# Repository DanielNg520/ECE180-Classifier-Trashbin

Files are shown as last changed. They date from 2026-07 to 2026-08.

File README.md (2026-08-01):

<p align="center">
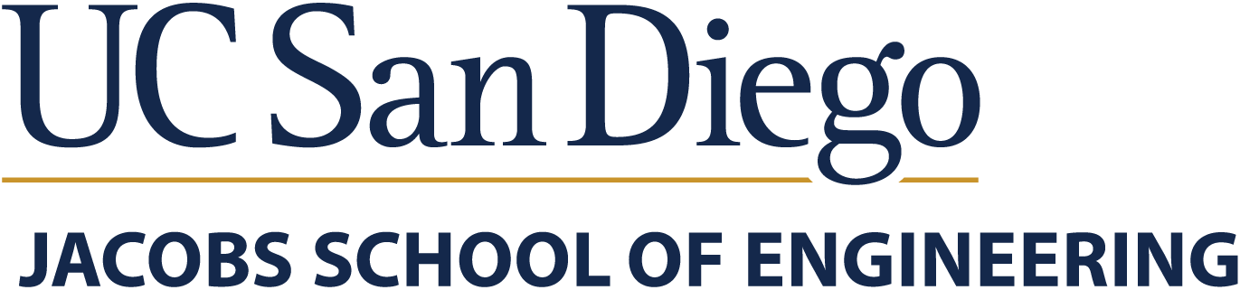
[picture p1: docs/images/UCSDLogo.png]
UC San Diego
  
</p>

# UCSD ECE 180 Summer 2026 Team 12 Final Project: Bin-ary Sort

*Waste sorting with computer vision, on the Arduino UNO Q.*

<p align="center">
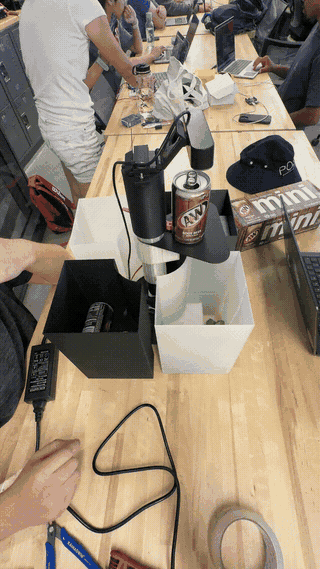
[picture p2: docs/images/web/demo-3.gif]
Bin-ary Sort classifying a can and rotating it to the correct bin
  
</p>

## Team Members

| Name | Major | Year |
|---|---|---|
| Colin Hua | ECE — Electrical Engineering | 2027 |
| Duy Nguyen | ECE — Computer Engineering | 2027 |
| Aram Zarate Ubario | ECE — Computer Engineering | 2027 |

**Course:** ECE 180 — Prof. Silberman, UC San Diego, Summer 2026

## Project Overview

Bin-ary Sorter is a smart trashbin that sorts your trash for you. You drop an
item in, and it lands in the right one of four bins. No phone, no app, no cloud
call, and nothing for the user to do.

A USB camera on top of the bin looks down and grabs a frame. A fine-tuned
**MobileNetV3-Large** classifies it into one of 30 waste classes from the Kaggle
dataset, that label collapses down to a bin number, and a NEMA-17 stepper
rotates the pole to that bin. All of the inference runs **on the board itself**,
on the UNO Q's Qualcomm Dragonwing Linux side. The STM32 MCU sitting on the same
board handles the real-time motor timing, and the two halves talk over Arduino's
**RouterBridge** RPC. Plug it in and it starts: both the classifier and the motor
controller come up on their own at boot.

If the model isn't sure, the bin doesn't guess. It sends the frame to our web
dashboard and asks a person which bin it should have been, and that answer goes
back into the training set for the next retrain.

## Goals

### Original Goals
- Train a transfer-learning waste classifier accurate enough to run quantized on an edge MPU
- Run inference fully on-device on the Arduino UNO Q (no cloud inference)
- Drive a rotating-pole sorting mechanism from the classification result
- Build a web dashboard showing live status and classification confidence

### Goals We Met
- MobileNetV3-Large fine-tuned to **89.1% test accuracy / 0.890 macro-F1** across 30 classes
- Exported to ONNX + three TFLite variants with **measured** per-variant accuracy, size, and latency
- Full on-device pipeline: camera → classify → bin index → stepper move, autostarted at boot
- **2-category sorting** through the single-axis rotating-pole chassis — later extended to 4 (see Stretch Goals)
- Web dashboard with correct/wrong human feedback (reinforced-learning loop)
- Second motor (servo arm) added to the mechanism late in the schedule

### Stretch Goals
- **4-category sorting** through the 2-axis double-motored rotating system — *Done*
- Federated learning across bins for a network effect — *Done*
- Higher-throughput continuous-feed sorting rather than one item at a time — *in progress*

## System Hardware

| Component | Purpose |
|---|---|
| Arduino UNO Q (Qualcomm Dragonwing QRB2210) | Primary compute — quad Cortex-A53 + Adreno 702, Debian Linux |
| STM32U585 MCU (Zephyr, on-board) | Real-time stepper/servo control, reached over RouterBridge RPC |
| USB webcam | Item capture at the drop chute |
| NEMA-17 stepper + driver | Rotates the sorting pole to the target bin |
| Servo arm | Second-stage actuation (added late; `SERVO_ENABLED` gate) |

## Model & Dataset

**Dataset:** [Recyclable and Household Waste Classification](https://www.kaggle.com/datasets/alistairking/recyclable-and-household-waste-classification)
— 30 classes, ~15k images, each class split into `default` (studio) and
`real_world` (cluttered) subsets.

We split it 70/15/15, stratified by *(class, subset)*, so the `real_world`
images show up in val and test in the same proportion as in training. This
matters more than it sounds: if we had let the studio shots dominate the test
set, our numbers would look better than what the bin's camera actually sees.

| Metric | Value |
|---|---|
| Test accuracy (fp32) | **89.08%** |
| Macro-F1 | **0.890** |
| Parameters | 4.24 M |
| `default` vs `real_world` accuracy | 89.2% vs 88.9% (no meaningful domain gap) |

Training is a two-stage fine-tune (head-only warmup, then full fine-tune) with
AdamW + cosine schedule, label smoothing 0.1, AMP, EMA weights, MixUp/CutMix,
class-balanced sampling, and augmentation meant to imitate a cheap camera. None
of that survives into deployment. What we export is one plain network.

### Quantization results

We re-scored every exported variant on the real test set instead of assuming the
quantized model kept the fp32 accuracy:

| Variant | Test acc | Size | Recommended threshold |
|---|---|---|---|
| fp32 | 89.08% | 17.1 MB | 0.75 |
| dynamic-int8 | 87.37% | 4.63 MB | 0.55 |
| **static-int8 (shipped)** | **86.36%** | **4.87 MB** | **0.80** |

**We ship static-int8.** It costs us 2.7 points of accuracy against fp32, but
it is 3.5× smaller, it is the fastest of the three on the board, and its
quantization ranges are calibrated on `real_world` training images so they line
up with what the camera sees. The confidence gate covers the accuracy we gave
up: at its measured 0.80 threshold, the predictions the bin accepts on its own
are still 95.0% correct, and everything below that goes to a person.

### Measured on-device latency

Benchmarked on the UNO Q itself (aarch64, quad Cortex-A53, TFLite XNNPACK CPU
delegate, 256×256 int8 input, 50 timed invocations after warmup):

| Threads | Median | Mean | Min – Max |
|---|---|---|---|
| 1 | 79.8 ms | 80.1 ms | 79.2 – 83.1 ms |
| **4 (shipped)** | **26.5 ms** | **27.3 ms** | **26.0 – 35.1 ms** |

`infer_uno_q.py` runs the interpreter with `num_threads=4`, so **~27 ms per
frame** is what a real classification costs us. That is nothing next to how long
the stepper takes to settle, so the model is never the slow part of a drop
cycle. This is inference only; camera capture and preprocessing sit on top of
it. We never needed the GPU delegate.

## Mechanical Design

Four bins sit in a round casing around a **rotating pole**. The pole always
takes the shorter way around to the target bin, clockwise or counter-clockwise,
and a tie goes clockwise. The move blocks until the pole actually gets there, so
when the software gets an acknowledgment it means the motion finished, not just
that the command was received.

We rebuilt the chassis once. The first design failed during seam testing and had
to be reprinted, which is the revision block you can see in the Gantt chart
below.

### Final design renders

| | |
|---|---|
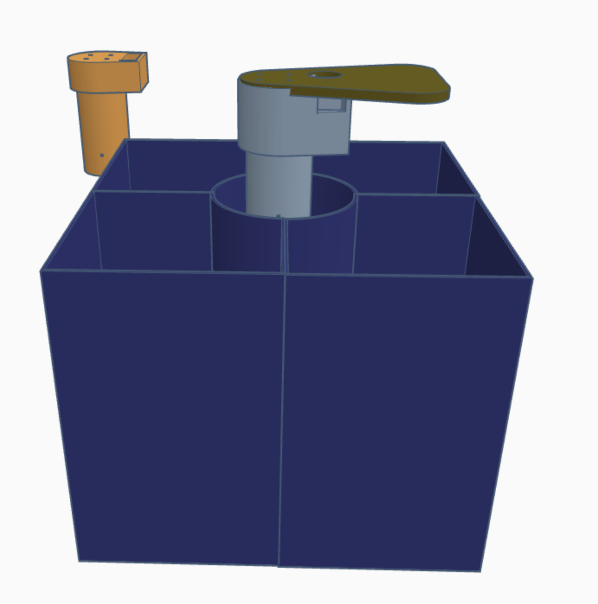
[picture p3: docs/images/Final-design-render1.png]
Final design render 1
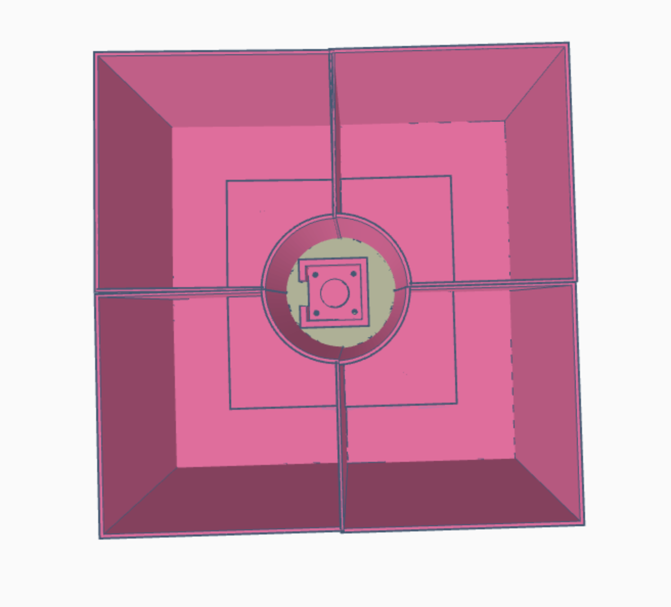
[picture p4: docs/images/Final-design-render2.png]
Final design render 2
|  |  |

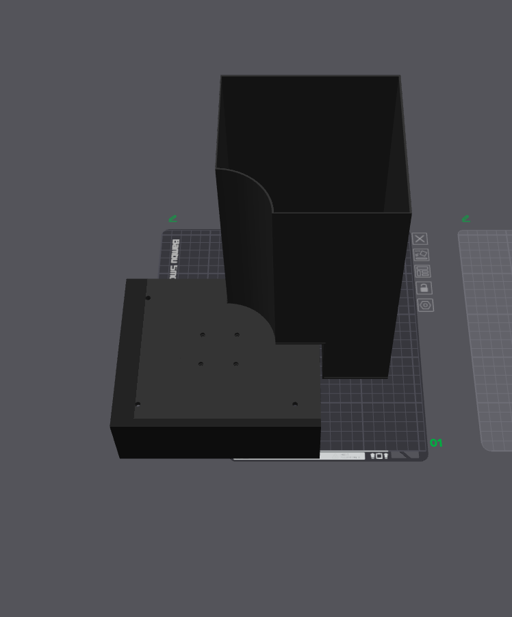
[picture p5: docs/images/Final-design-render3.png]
Final design render 3


### Double-motored rotating pole

This is the 2-axis mechanism that got us from 2 categories to 4. The stepper
rotates the pole to the target bin, then the servo arm sweeps the item off the
platform and into it.

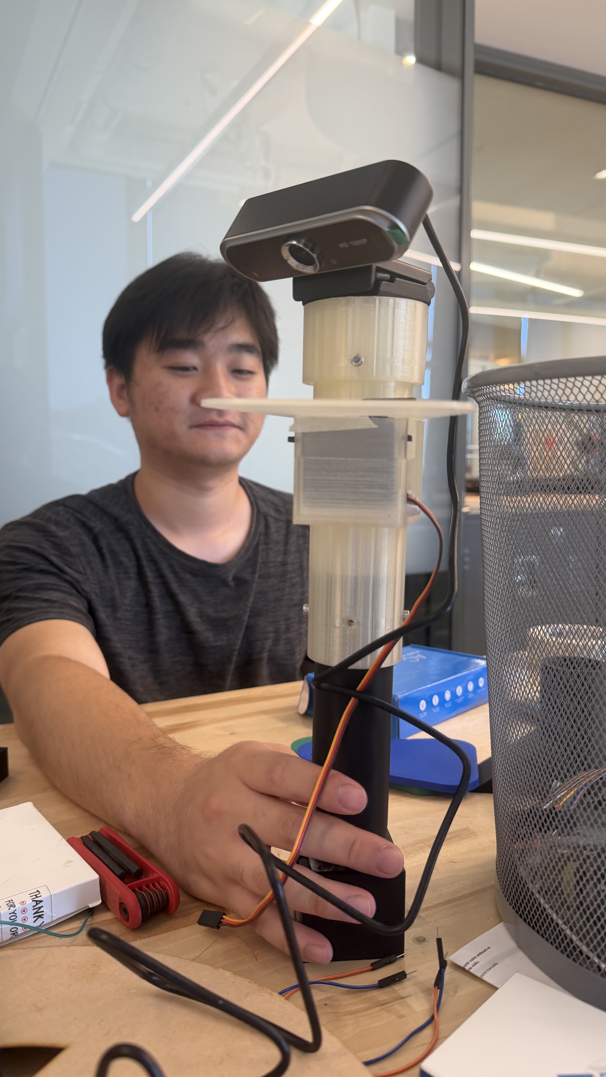
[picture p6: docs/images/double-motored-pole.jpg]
Double-motored rotating pole assembly


### Printable parts

Every part of the chassis is in [`STL/`](STL/):

| File | Part |
|---|---|
| `Bottom_column.stl` | Base column the rotating pole sits on |
| `Camera_mount.stl` | Camera mount at the top of the pole |
| `Camera_platform.stl` | Platform the camera looks down onto |
| `Camera_securer.stl` | Retainer clamping the camera to the mount |
| `Component_tray.stl` | Tray holding the UNO Q, driver, and buck converters |
| `Component_lid.stl` | Lid for the component tray |
| `Nema_holder.stl` | NEMA-17 stepper bracket |
| `Servo_holder.stl` | MG996R servo bracket |
| `Trash_bins.stl` | The four-bin round casing |
| `Wooden_rim.svg` | Laser-cut outer rim (2D profile, not printed) |

## Demo

Our first end-to-end run, sorting into 2 categories with the single-axis pole:

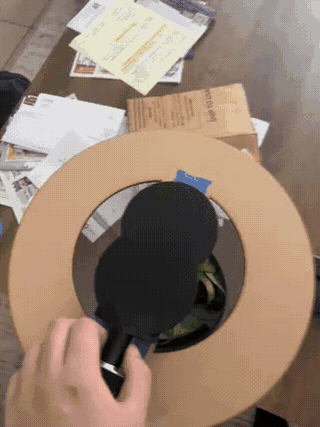
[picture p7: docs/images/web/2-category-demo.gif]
Two-category sorting demo


And the finished bin sorting into all 4, using the double-motored mechanism:

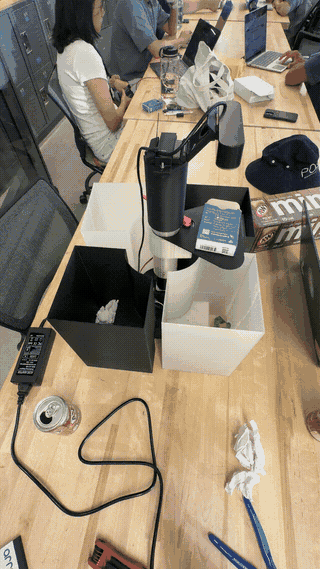
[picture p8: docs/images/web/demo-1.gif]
Sorting demo 1


Sorting demo 2

Sorting demo 3

*(These are downscaled for the page. Full-resolution originals are in
[`docs/images/`](docs/images/).)*

## Build Guide

How to go from a pile of printed parts to a working bin.

### 1. Power distribution

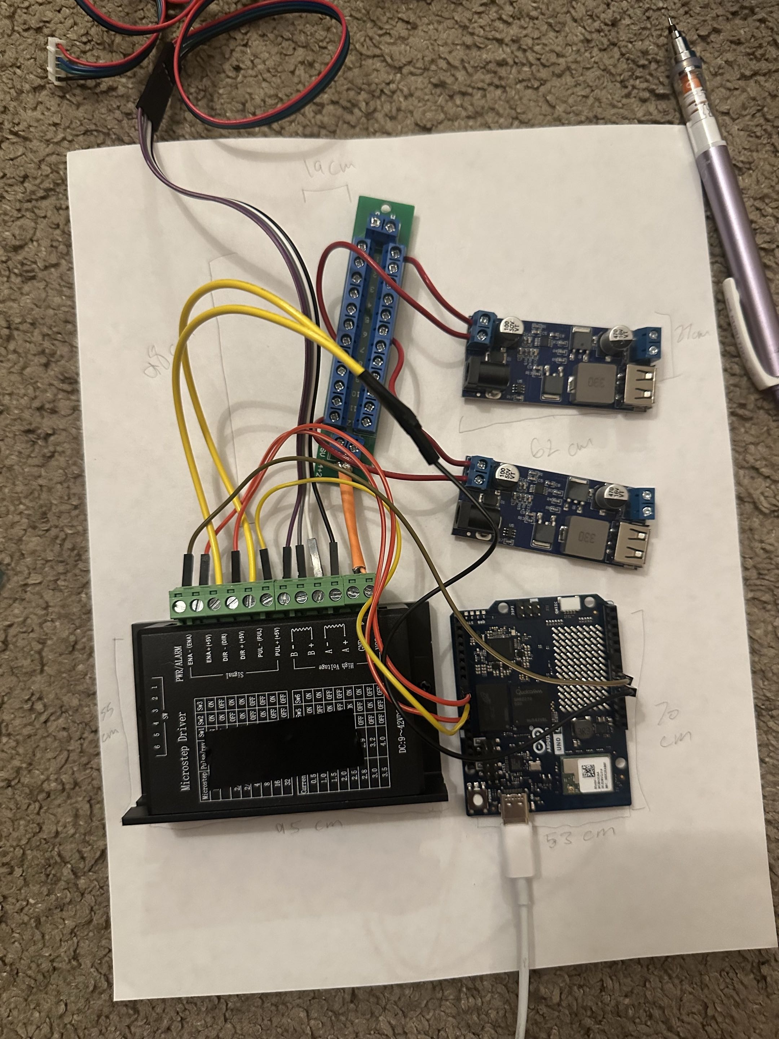
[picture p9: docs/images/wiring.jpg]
Wiring of the UNO Q, stepper driver, servo, and buck converters


Everything runs off one AC/DC supply into a single terminal-block splitter, and
that terminal fans out three ways:

| Branch | Feeds | Notes |
|---|---|---|
| 12 V direct | NEMA-17 stepper driver | Motor supply pins on the driver, not the logic side |
| 12 V → 5 V buck #1 | Arduino UNO Q | Board logic and the STM32 side |
| 12 V → 5 V buck #2 | MG996R servo, exclusively | Deliberately off the UNO Q's rail. The servo's stall current would brown the board out. |

Keep the servo on its own converter. That separation is the whole point of
having two bucks rather than one.

### 2. Signal wiring

- **Stepper driver.** Wire Enable (`ENA`), Direction (`DIR`), and Pulse (`PUL`)
  from the driver to the UNO Q's digital I/O. Ours are **PUL = 2, DIR = 3,
  ENA = 4**, common-anode active-LOW, with the driver DIPs on 1/8 microstep
  (1600 steps/rev, so 400 steps per bin).
- **Servo.** Connect the servo's PWM signal wire to its control pin on the
  UNO Q. Ours is **D6**, picked to stay clear of the stepper's 2/3/4.

### 3. Base enclosure

1. Arrange all the wired electronics inside the base enclosure
   (`Component_tray.stl`).
2. Put the cover (`Component_lid.stl`) over the tray to close everything in.
3. Install four M3 heat-set inserts into the marked holes on top of the lid with
   a soldering iron. Once they've cooled, bolt the stepper bracket
   (`Nema_holder.stl`) to the lid with four M3 screws.

### 4. Camera apparatus

1. Connect the adjustable shaft to the column (`Bottom_column.stl`) and pin it
   at whichever of the pre-spaced height holes gives you the elevation you want.
2. Slide the servo into its housing (`Servo_holder.stl`) on the column.
3. Mount the camera housing (`Camera_mount.stl`) and the tail platform
   (`Camera_platform.stl`) on top of the column/servo assembly, then clamp the
   camera down with `Camera_securer.stl`.
4. Fasten the rest of the camera parts together with M3 screws wherever the
   print calls for them. Rigidity matters here: the camera has to stay pointed
   at the same spot or the framing drifts away from what the model was
   calibrated on.

### 5. Final setup

Position the four collection baskets (`Trash_bins.stl`, with `Wooden_rim.svg`
laser-cut as the outer rim) around the outer edge of the machine so each one
sits under its bin position. Then power on: the classifier and motor controller
start themselves, and the bin is ready to sort.

### Two power problems that cost us time

#### The camera needs a powered USB hub

The UNO Q **cannot power the USB camera while the board itself is being powered
through the pin header.** There isn't enough left over on its USB rail. The
camera has to hang off a powered hub instead:

```
UNO Q ──USB-C──> powered USB hub ──USB-A──> camera
```

If you plug the camera straight into the board while the board is running off
the buck converter, it will enumerate, look fine, and then drop out as soon as
anything draws current.

#### Size the supply above 66 W

Our demo pulls about **66 W** at peak: stepper holding torque, servo actuation,
board, and camera all at once. We ran it on a **60 W** supply, and that gap is
not a margin note, it is an actual failure mode. When the rail sags, some UNO Q
pins get stuck **LOW** and stay there. In our case it was almost certainly the
**DIR** pin. The stepper still stepped just fine, but the shaft would only ever
turn one direction and never reverse.

So if the pole rotates but refuses to go counter-clockwise, **check your power
supply before you touch the sketch.** We lost a day to this. A 12 V supply with
real headroom over 66 W (8 A, around 96 W) makes the whole symptom disappear.

## Accomplishments

### On-device classification
The Linux side copies the notebook's `eval_tf` preprocessing exactly: resize the
shorter side to ~293, center-crop to 256, ImageNet mean/std. We were careful
about this because a preprocessing mismatch is the most common reason a model
works in Colab and falls apart on the device. The model, the labels, and the
thresholds all get read out of the export directory, so putting a retrained
model on the bin is just a file copy.

### Two-processor split
The STM32 on the UNO Q is not a serial tty. The only way to reach it is Arduino's
**RouterBridge**, and that bridge only exists inside an Arduino App Lab app. So
motor control had to become its own App (`deploy/motor_app/`, installed at
`~/ArduinoApps/nema17`). It opens an HTTP command port on `:8071`, the classifier
POSTs a target bin to it, and the App turns that into a `Bridge.call("sort", bin)`
down to the MCU.

### Plug-and-play autostart
We wanted the bin to just work when you plug it in, but installing a systemd
service needs a sudo password the board won't give us. So autostart is two
`@reboot` entries in the `arduino` user's crontab. `start_motor_app.sh` waits for
docker and the App Lab daemon to be up before starting the motor App, and
`run_trashbin.sh` runs the camera loop inside a wrapper that restarts it if it
dies. If the motor App happens to be down, sort calls just fail quietly instead
of taking the classifier with them.

### Confidence-gated clarification loop
The raw softmax from a label-smoothed model is not a real probability, so we fit
**temperature scaling** on the val set (T = 0.55), sweep thresholds, and then
re-measure the threshold separately for each TFLite variant. The rule we use is
the lowest threshold whose auto-accepted predictions are still ≥95% correct,
which gets us the most coverage we can have at that accuracy floor. Anything
under the threshold gets posted to the webapp with its top-k guesses, a person
picks the right label, and that correction goes into the shared training set.

### Web dashboard
Recent classifications with confidence bars, a review queue of the low-confidence
frames with correct/wrong buttons, and status tiles for the web server, the
board, and the model.

**Live at [ece180.duythe.dev](https://ece180.duythe.dev).**

## Challenges & Solutions

| System | Challenge | Solution |
|---|---|---|
| Chassis | Original design failed under load / seam testing | Full chassis revision and reprint before integration |
| MCU access | STM32 is not exposed as a serial device on the UNO Q | Moved motor control into an Arduino App Lab app talking over RouterBridge RPC |
| Autostart | systemd install requires a sudo password | Two `@reboot` crontab entries with self-restarting wrappers |
| Python env | Board Python is externally managed, no venv available | `pip install --user --break-system-packages`, `PYTHONPATH` pointed at `~/.local` |
| Quantization | int8 shifts logits, invalidating a single fixed threshold | Re-measured accuracy *and* threshold per exported variant |
| Confidence | Label smoothing makes softmax overconfident | Temperature scaling fitted on val, threshold chosen by measured accept-accuracy |
| Power | 60 W supply against a 66 W demo draw — pins pinned LOW (DIR), so the shaft only turned one way | Diagnosed as brownout rather than a firmware bug; split the rails across two bucks and sized the supply above the real draw |
| Camera power | UNO Q can't power the USB camera while itself powered through the pin header | Camera moved behind a powered USB hub off the board's USB-C |

## Lessons Learned

- Measure it, don't assume it. Accuracy, latency, and the confidence threshold all had to be re-measured for every export variant. None of them carried over from the fp32 model the way we expected.
- Matching your preprocessing between training and deployment is worth more than any clever training trick you can add on top.
- Assume the mechanism will need a revision. Our first chassis was wrong, and the only reason the schedule survived is that we had already planned time for a reprint.
- Research the platform before you architect around it. The RouterBridge and App Lab constraint on the UNO Q reshaped our entire software design, and it would have been a lot cheaper to find that out in week one.
- Sometimes a good product design solves a lot of engineering problems.
- Check your power budget before you start debugging code. We spent a day chasing a stepper that would only turn one direction, and it was a 60 W supply under a 66 W load the whole time.

## Next Steps

- **Federated learning:** aggregate corrections across deployed bins so every bin improves from every other bin's mistakes
- **Higher-resolution / continuous feed:** sort a stream of items rather than one drop at a time
- **Recover the int8 accuracy gap:** quantization-aware training, or fp16 on the Adreno 702 GPU delegate — at 27 ms per frame there is plenty of latency headroom to spend on a more accurate variant

## Gantt Chart

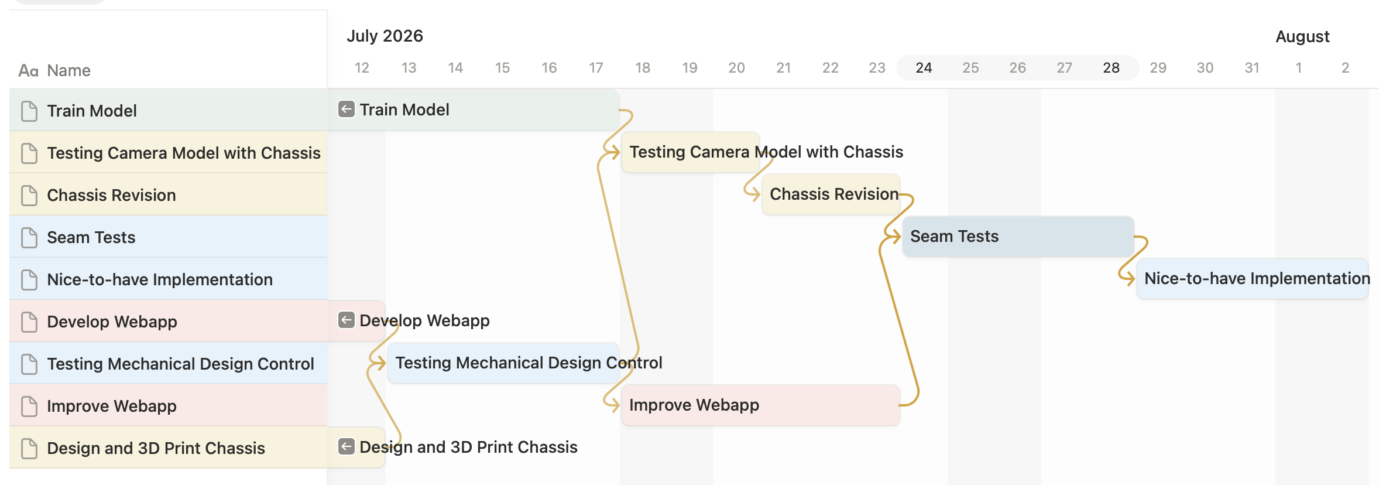
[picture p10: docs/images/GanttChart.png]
Project Gantt chart


| Task | Window (July 2026) |
|---|---|
| Train Model | 12 – 18 |
| Design and 3D Print Chassis | 12 – 13 |
| Develop Webapp | 12 – 13 |
| Testing Mechanical Design Control | 13 – 17 |
| Improve Webapp | 18 – 23 |
| Testing Camera Model with Chassis | 18 – 20 |
| Chassis Revision | 20 – 22 |
| Seam Tests | 22 – 26 |
| Nice-to-have Implementation | 28 – Aug 2 |

## Videos and Resources

- **Live dashboard:** [ece180.duythe.dev](https://ece180.duythe.dev)
- **Sorting demos:** full-resolution clips in [`docs/images/`](docs/images/) (`2-category-demo-full.gif`, `demo-1-full.gif`, `demo-2-full.gif`, `demo-3-full.gif`)
- **Dataset:** [Recyclable and Household Waste Classification](https://www.kaggle.com/datasets/alistairking/recyclable-and-household-waste-classification) on Kaggle
- **Full training pipeline:** [`ECE180_Complete_Notebook.ipynb`](ECE180_Complete_Notebook.ipynb)
- **Printable parts:** [`STL/`](STL/)

## Project Reconstruction

### Hardware Requirements
- Arduino UNO Q
- USB webcam **+ a powered USB hub** (the board cannot power the camera on its own — see [Build Guide](#build-guide))
- NEMA-17 stepper + stepper driver (1/8 microstep)
- MG996R servo (second stage)
- 12 V power supply — **8 A / ~96 W recommended**; the demo draws ~66 W and a 60 W unit browns out
- One distribution terminal + two 12 V → 5 V buck converters (one for the UNO Q, one for the servo)
- 3D-printed chassis — all STLs in [`STL/`](STL/), see [Printable parts](#printable-parts)

### Training

1. Set the Colab runtime to **T4 GPU**.
2. Add Colab Secrets: `GITHUB_TOKEN`, `KAGGLE_USERNAME`, `KAGGLE_KEY`.
3. Run `ECE180_Complete_Notebook.ipynb` top to bottom — **run the export cell (Cell 13) last**, since `litert-torch` pins torch versions and can disturb the training environment.

The dataset downloads once via kagglehub into Google Drive; checkpoints and
results persist there, and training is multi-session safe — if Colab
disconnects, re-running resumes from the last epoch including EMA state.

### Deployment

1. Connect to the board over the standard UNO Q SSH login (`ssh arduino@uno-q.local`,
   or the board's IP on the same network) and copy `deploy/` plus the exported
   `.tflite` and `labels.txt` across with `scp`.
2. Install host deps to the user site: `pip install --user --break-system-packages ai-edge-litert opencv-python-headless numpy pillow requests`.
3. Install the motor App to `~/ArduinoApps/nema17` and `arduino-app-cli app start` it.
4. Verify the stepper pins in `deploy/motor_app/sketch/sketch.ino` — **PUL=2 / DIR=3 / ENA=4**, common-anode active-LOW, 1600 steps/rev → 400 steps/bin.
5. Add the two `@reboot` crontab entries (`start_motor_app.sh`, `run_trashbin.sh`).
6. Set `MOTOR_ENABLED=1`, `MOTOR_URL=http://127.0.0.1:8071`, plus `TEMPERATURE` and `CONFIDENCE_THRESHOLD` for the shipped variant.

Full technical detail, file-by-file, is in [`docs/TECHNICAL.md`](docs/TECHNICAL.md)
and [`docs/MOTOR_CONTROL.md`](docs/MOTOR_CONTROL.md).

### Troubleshooting

| Problem | Fix |
|---|-----|
| Sort RPCs come back `landed=N` but the pole never moves | The sketch's pin constants don't match how the driver is actually wired. Check `PUL`/`DIR`/`ENA` against the board. |
| The pole only ever turns one direction and never reverses | Almost always power, not code. Your supply is under the ~66 W draw and a pin (usually `DIR`) is stuck LOW. |
| The pole turns the wrong way | Swap the `CW` / `CCW` constants in the sketch. |
| The pole over- or under-shoots a bin | `STEPS_PER_REV` doesn't match the driver's DIP microstep setting. Rescale it. |
| Accuracy is far worse on the board than it was in Colab | Preprocessing mismatch. The device path has to match `eval_tf` exactly. |
| Motor calls silently do nothing | The App Lab app isn't running. Start it with `start_motor_app.sh`. |
| The camera enumerates and then drops out | It's plugged straight into the board. Move it behind a powered USB hub. |

After any sketch change: `arduino-app-cli app restart ~/ArduinoApps/nema17`.

## Repository Structure

```
.
├── README.md                        # this report
├── ECE180_Complete_Notebook.ipynb   # Full pipeline: download → train → eval → export
├── deploy/                          # UNO Q runtime (camera loop, inference, motor App)
├── webapp/                          # dashboard + clarification service
├── exports/                         # ONNX model, labels.txt, quantization + calibration reports
├── results/                         # test_results.json, domain_shift.json, confusion_matrix.png
├── STL/                             # printable chassis parts + laser-cut rim
└── docs/
    ├── TECHNICAL.md                 # implementation reference, file by file
    ├── MOTOR_CONTROL.md             # motor command path + as-built firmware log
    ├── BACKGROUND_ML.md             # appendix: the ML side, explained from zero
    ├── BACKGROUND_ELECTROMECHANICAL.md  # appendix: motors, drivers, power
    └── images/                      # demo GIFs, renders, wiring photo, Gantt chart
```

### Documentation

Everything supporting this report lives in [`docs/`](docs/):

| Document | What's in it |
|---|---|
| [`TECHNICAL.md`](docs/TECHNICAL.md) | The implementation, file by file: training setup, repo layout, deployment steps, and the clarification loop |
| [`MOTOR_CONTROL.md`](docs/MOTOR_CONTROL.md) | How a motor command travels from a laptop to the two motors, the full command surface, and our as-built firmware notes (servo overheating, motion ramp, manual zeroing) |
| [`BACKGROUND_ML.md`](docs/BACKGROUND_ML.md) | Appendix. The machine-learning side written from zero: dataset splitting, transfer learning, the training recipe, calibration, and quantization |
| [`BACKGROUND_ELECTROMECHANICAL.md`](docs/BACKGROUND_ELECTROMECHANICAL.md) | Appendix. The other half, also from zero: power, grounding, servos, steppers, microstepping, and how software turns into motion |

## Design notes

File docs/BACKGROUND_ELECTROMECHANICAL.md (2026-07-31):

# Electromechanical Study Notes — Trashbin Sorter

A from-zero guide to the *non-camera* half of this project: motors, drivers,
power, and how the microcontroller drives them. Written for someone who knows
software but has never touched a motor. Everything here maps to the actual
parts in this build and to `deploy/motor_app/sketch/sketch.ino`.

Read top to bottom the first time — each section builds on the last.

> **As-built wiring (2026-07-23).** The pin examples further down are generic
> teaching examples. The *actual* firmware that ships is the Arduino App Lab
> app `deploy/motor_app/sketch/sketch.ino`. (An earlier standalone sketch,
> `motor_control.ino`, drove the MCU directly over serial; it was removed once
> the App Lab RouterBridge became the only supported path — see the README's
> *On-Device Deployment* section for why.) The
> bench-confirmed stepper wiring is **PUL=2, DIR=3, ENA=4** (common-anode,
> active-LOW) at 1/8 microstep → **1600 steps/rev = 400 steps/bin**. The servo
> arm and homing switch are **not wired yet** (`SERVO_ENABLED` / `HOMING_ENABLED`
> are off in the sketch). When you wire the servo, pick a pin that does **not**
> collide with the stepper's 2/3/4.

---

## 0. The 60-second mental model

Think of it in layers, like a software stack:

```
Camera + classifier (Linux)        "this is a plastic bottle -> bin 1"
        |  serial: "SORT 1\n"
Microcontroller / MCU (the sketch)  decides angles, counts pulses, timing
        |  logic signals: STEP / DIR / PWM  (tiny 3-5V wires, no power)
Motor DRIVERS (stepper driver, servo internals)   the "muscle amplifiers"
        |  fat wires, lots of current
MOTORS (NEMA 17 stepper, MG996R servo)            actually move things
        ^
POWER (12V supply -> buck converters)             feeds the muscle
```

Two ideas that trip up every beginner, so internalize them now:

1. **Signal wires vs power wires are different worlds.** The MCU never powers a
   motor directly — it can only supply a few milliamps, like a whisper. It
   sends a *command* (a small voltage) to a **driver**, and the driver opens
   the floodgates from the big power supply to the motor. Blowing this up:
   plugging a motor straight into an MCU pin fries the pin instantly.

2. **"Ground" is the shared zero.** Voltage is always measured *relative* to
   something. Every part must agree on where "0V" is, or signals are
   meaningless. That's why "tie all grounds together" is repeated everywhere.

📺 *Watch first (20 min, the single best beginner primer):*
- "Electronics Basics" playlist by **GreatScott!** on YouTube — start with
  "How Voltage, Current & Resistance work". Search: `GreatScott electronics basics`
- Or **Branch Education** "How does a Transistor Work" for the intuition of a
  small signal controlling big power.

---

## 1. Electricity fundamentals (the absolute minimum)

You need exactly four words: **voltage, current, ground, and PWM.**

- **Voltage (V, volts)** — "electrical pressure." Our supply is 12V. Logic
  signals are 3.3V or 5V. Think water *pressure* in a pipe.
- **Current (A, amps / mA milliamps)** — "flow rate." Motors are thirsty
  (0.5–2A). Logic pins provide almost none (~0.02A). Think water *flow*.
- **Ground (GND, 0V)** — the reference everything measures against. The
  "return path" — current flows *out* of the supply, through the motor, and
  *back* to ground. A circuit must be a complete loop.
- **A "short circuit"** is when + connects directly to − with nothing in
  between. Current spikes, things get hot/burn. This is what you're avoiding
  when you wire carefully.

Analogy that actually works: **Voltage = water pressure, Current = flow rate,
Wire = pipe, Ground = the reservoir it all drains back into, Resistor = a
narrow section of pipe.**

Ohm's Law, the one equation: **V = I × R** (Voltage = Current × Resistance).
You rarely compute it by hand here, but it explains *why* resistors exist and
why thin wires get hot.

📖 *Free resources:*
- **SparkFun** "What is a Circuit?" and "Voltage, Current, Resistance, and
  Ohm's Law" — learn.sparkfun.com (search those titles). Best written intros
  that exist, with pictures.
- **Khan Academy** → "Electrical engineering" → "Circuit analysis" for the
  math side if you want it (optional for this project).
- 📺 **The Engineering Mindset** "Voltage explained" and "Current explained".

---

## 2. Power: the 12V supply and the buck converters

Your parts: **one 12V 5A power supply** and **two 12V→5V buck converters.**

### Why not just one voltage?
Different parts want different voltages:
- The **stepper motor + its driver** want **12V** (higher voltage = more speed
  and torque). Fed straight from the supply.
- The **servo** wants **~5–6V**. Give it 12V and it dies.
- The **logic** (MCU side) wants 3.3V/5V.

A **buck converter** is a small board that efficiently steps a higher voltage
DOWN to a lower one (12V → 5V) *without* wasting most of the energy as heat
(unlike a plain resistor). "Buck" = step-down. Its cousin "boost" = step-up.

Most buck modules have a tiny screw (**potentiometer**) you turn to set the
output voltage. **You set this with a multimeter BEFORE connecting anything:**
power the input, probe the output, turn the screw until it reads 5.0V.

### Why *two* bucks?
Isolation. Motors create nasty electrical "noise" — sudden current spikes when
they start/stop that make the voltage sag and spike. If your servo and your
logic share the same 5V rail as a motor, that noise can reset your MCU or make
the servo jitter. Two separate bucks = one clean rail for logic, one for the
servo's muscle. (This is *the* most common cause of "my board randomly
reboots" in student projects.)

### The "5A" number — a budget
Amps is a *budget*, not a fixed draw. The supply can deliver *up to* 5A. Add up
what everything pulls at once (stepper ~1.5A + servo up to ~1A stall + logic
~0.5A ≈ 3A) and stay comfortably under 5A. You're fine here.

⚠️ **Safety:** 12V at 5A won't shock you (too low voltage to feel), but it
*can* deliver enough current to overheat a wire or scorch a component if you
short it. Never wire with the power plugged in. Double-check + and − before
first power-on.

📺 *Free resources:*
- **GreatScott!** "DIY Buck Converter" / "What is a buck converter?" — shows
  exactly what these boards do.
- **SparkFun** learn: "How to Power a Project" — walks through picking voltages
  and adding them up.
- 📺 **DroneBot Workshop** "Powering Your Projects" — extremely beginner
  friendly, ~20 min.

---

## 3. Grounding: the rule that silently ruins projects

**Every ground must connect to every other ground.** The 12V supply ground,
both buck grounds, the stepper driver ground, the servo ground, and the MCU
ground — all one connected node, often called "common ground."

Why: a signal wire says "5V" only *relative to its ground*. If the MCU's ground
and the driver's ground aren't the same node, the driver sees a garbage voltage
and behaves randomly. This is invisible — nothing looks wrong — which is why it
eats hours. Wire grounds first, deliberately.

You do **not** connect the positives together (12V and 5V stay separate). Only
grounds are shared.

📺 *Free resource:* Search `DroneBot Workshop common ground` — he demonstrates
this failure live.

---

## 4. Motors, part 1: the SERVO (MG996R)

A servo is the *easy* motor — it's the "hello world" of actuators.

### What it is
A small geared motor with built-in electronics that holds a **commanded
angle**. You tell it "go to 90°" and it goes there and holds. Range is usually
0–180°. In this project it's the **arm that sweeps trash off the platform.**

### The three wires
- **Brown/Black = Ground**
- **Red = Power** (5–6V — from a buck, NOT the MCU's 3.3V pin; the MG996R can
  pull ~1A when pushing hard and would brown out the board)
- **Orange/Yellow = Signal** (goes to an MCU pin — this is *just* a signal,
  tiny current)

### How you control it — PWM
**PWM = Pulse Width Modulation.** The MCU sends a repeating pulse ~50 times a
second (every 20ms). The *width* of the pulse encodes the angle:
- ~1.0ms wide → 0°
- ~1.5ms wide → 90°
- ~2.0ms wide → 180°

You never write this by hand — Arduino's **`Servo` library** does it. In the
sketch it's literally:
```cpp
#include <Servo.h>
Servo arm;
arm.attach(9);        // signal on pin 9
arm.write(160);       // go to 160 degrees
```
That's the whole API. In `sketch.ino`, `ARM_REST` and `ARM_SWEEP` are just two
angles, and `sweepArm()` moves between them.

### Gotchas
- **Power it from the buck, not the board.** #1 servo mistake.
- Common ground with the MCU (section 3).
- The MG996R is strong (~10 kg·cm) and will happily strip its own plastic gears
  or bend your arm if it jams — don't command it into a hard stop repeatedly.

📺 *Free resources (do these — servos are very "watch and learn"):*
- **DroneBot Workshop** "Servo Motors with Arduino" — the definitive beginner
  video.
- Official **Arduino** docs: search `Arduino Servo library` → the "Sweep" and
  "Knob" example sketches. Run "Sweep" first — it's 10 lines and moves a servo
  back and forth. Instant win.
- **HowToMechatronics** "How Servo Motors Work & How To Control Servos with
  Arduino" — great article + video with the PWM diagrams.

---

## 5. Motors, part 2: the STEPPER (NEMA 17) + its driver

Steppers are the *interesting* one and where most of your learning is.

### What "NEMA 17" means
Just a **size standard** — the faceplate is 1.7 inches. Says nothing about
power. It's the common hobby-CNC/3D-printer motor.

### Why a stepper (vs a servo or plain motor)?
A stepper moves in exact, countable **steps** — typically **200 full steps per
full rotation** (1.8° each). No feedback sensor needed: if you send 200 pulses,
it turned exactly once. That precision is why it rotates your **pole** to face a
specific bin. A plain DC motor just spins; a servo only reaches ~180°; a stepper
can rotate continuously *and* precisely.

### Steps, microsteps, and your "400 per bin"
The driver can split each physical step into **microsteps** for smoothness.
Your driver set to "8 microstep" means 8 microsteps per step:
`200 steps × 8 = 1600 microstep-pulses per full revolution.`
Four bins around a circle = 90° each = a quarter turn =
`1600 ÷ 4 = 400 pulses per bin.` That's `STEPS_PER_BIN = 400` in the sketch.
**This is the core idea: rotating to a bin = sending a counted number of
pulses.**

### The driver (your black "Microstep Driver" box, a TB6600 class)
The stepper has 4 wires (two coils, A and B) that must be energized in a
precise dance. Doing that from an MCU directly is impossible — the **driver**
does it. You only give the driver three simple logic signals:

- **PUL (Pulse / STEP)** — one pulse = one microstep. Send 400 pulses → moves
  one bin. This is the whole motion primitive.
- **DIR (Direction)** — HIGH or LOW picks clockwise vs counterclockwise.
- **ENA (Enable)** — turns the motor's holding power on/off.

In code, "send a pulse" is just:
```cpp
digitalWrite(PIN_PUL, LOW);  delayMicroseconds(800);
digitalWrite(PIN_PUL, HIGH); delayMicroseconds(800);   // that's ONE step
```
Do that 400 times → one bin over. That's exactly `stepPulse()` and `rotate()`
in the sketch. (Ours is "active-LOW", see section 6, so LOW=on.)

### The two sets of DIP switches on the driver
Your driver has 6 little switches:
- **SW1–3 set microstepping** — we chose "8" (1600 pulse/rev) for clean 400/bin.
- **SW4–6 set current limit** — how many amps the driver feeds the motor. Set
  this to your motor's rated current (on its label, ~1.5A typical). **Too high =
  motor cooks; too low = weak, skips steps.** The table is printed on the driver
  and I put the exact switch positions in our earlier chat.

### "Losing steps" and why you home
A stepper is **open-loop** — no sensor tells it where it actually is. If it
jams, or you cut power, it forgets its position. So on boot the sketch drives
the pole until it hits the **physical zero stop** (a switch), and *declares that
position bin 0*. Everything is counted from there. That's `homePole()`. This is
the single most important concept for reliability.

📺 *Free resources (spend real time here):*
- **DroneBot Workshop** "Stepper Motors with Arduino" — long, thorough, perfect.
  Watch the whole thing.
- **How To Mechatronics** "How Stepper Motors Work" — best animation of the
  coil dance; and his "Control Stepper with A4988" article (same STEP/DIR idea
  as your TB6600).
- **DroneBot Workshop** "Big Stepper Motors with Arduino" — specifically covers
  **TB6600-style** drivers like yours (wiring the ± inputs, DIP switches).
- Search `TB6600 wiring common anode common cathode` — a couple of short blog
  posts explain the ± input wiring we used.

---

## 6. The wiring detail we chose: "active-LOW / common-anode"

Your driver's inputs are **opto-isolated** (a tiny internal LED per signal,
which electrically separates the driver from your MCU — good, it protects your
board). Each input has a **+** and a **−** terminal: PUL+/PUL−, DIR+/DIR−,
ENA+/ENA−. The LED lights (signal "on") when current flows from + to −.

These LEDs are designed for ~5V, but the Uno Q's MCU pins output **3.3V** — a
bit weak to drive the + side reliably. The fix ("common-anode" wiring):
- Tie all the **+** terminals to a steady **5V** (from a buck).
- Connect each **−** terminal to an MCU pin.
- Now the signal turns *on* when the MCU pin goes **LOW** (0V), because that's
  when current flows through the LED. Hence **active-LOW**.

That's why the sketch has `ASSERT = LOW` — it's not a mistake, it's this wiring.
Don't overthink it; just wire + to 5V, − to the pins, and the code already
matches.

📖 Search `optocoupler explained` (GreatScott has one) if you want to see why
that little LED-and-sensor keeps motor noise from frying your MCU.

---

## 7. How software becomes motion (the full path)

Trace one item through the whole stack — this ties your camera world to the new
one:

1. **Item lands on platform.** Camera sees motion → `camera_loop.py` grabs a
   frame (your domain).
2. **Classifier** says `plastic_water_bottles`, 0.92 confidence (your domain).
3. **`bin_map.py`** turns that label into `bin 1` (containers).
4. **`motor_bridge.py`** POSTs `{"bin": 1}` to the motor App on
   `http://127.0.0.1:8071/sort`, which relays it to the MCU over the
   RouterBridge as `Bridge.call("sort", 1)`.
5. **`sketch.ino`** receives it, computes the stop position
   `(1 + OFFSET) % 4`, and calls `rotate(400 × n, dir)` — literally toggling the
   PUL pin that many times.
6. The **driver** turns those pulses into the coil dance → the **NEMA 17**
   turns the **pole** to the right spot.
7. The sketch calls `sweepArm()` → the **servo** pushes the item into the bin.
8. Sketch sends `OK 1\n` back so Python knows it can handle the next item.

Every arrow is a thing you can test in isolation (see section 8).

---

## 8. Hands-on learning path (do these in order — don't read, *build*)

You learn this by making one thing move at a time. Cheap and safe:

1. **Blink an LED** with the MCU. Proves you can flash code and toggle a pin.
   (Arduino "Blink" example.) `digitalWrite` is *the* primitive behind
   everything else.
2. **Run the servo "Sweep" example.** Power the servo from your buck. Watch the
   arm move. You now understand PWM by feel.
3. **Spin the stepper a known amount.** Wire the driver, set the DIPs, send 1600
   pulses, confirm it makes *exactly one* full turn. Then 400 → a quarter turn.
   This is the "aha" moment.
4. **Add the DIR pin** — make it go one way, then back.
5. **Add the zero-stop switch** — read it with `digitalRead`, print HIGH/LOW as
   you press it. Then combine into homing.
6. **Send commands over Serial** — open the Serial Monitor, type `SORT 2`, watch
   it move. (Our sketch already does this.)
7. **Connect the Python side** and let the classifier drive it.

Each step is ~30 min and independently satisfying. If step N breaks, you know
it's step N's wiring — that's the whole point of going one at a time.

📺 *The one channel to subscribe to:* **DroneBot Workshop**. His Arduino +
motors + power tutorials are the clearest free material on exactly this stack.
Second: **How To Mechatronics** for animations, **GreatScott!** for the
electronics theory, **SparkFun/Adafruit learn sites** for written references.

---

## 9. Glossary (skim when a word stumps you)

- **MCU / microcontroller** — the small "brain" chip that runs your sketch and
  toggles pins. On the Uno Q it's the STM32 half.
- **Driver** — power amplifier between MCU signals and a motor.
- **Stepper** — motor that moves in exact counted steps.
- **Servo** — motor that holds a commanded angle (0–180°).
- **NEMA 17** — a motor *size* (1.7" face), not a spec.
- **PWM** — encoding a value (servo angle, or motor speed) as pulse width.
- **STEP/PUL, DIR, ENA** — the three stepper-driver control signals.
- **Microstepping** — splitting one physical step into smaller ones for
  smoothness.
- **Buck converter** — steps a voltage down efficiently (12V→5V).
- **Ground / GND / common ground** — the shared 0V reference; tie them all
  together.
- **Open-loop** — no position feedback; why we home to a zero stop.
- **Homing** — driving to a known physical reference on startup to sync
  position.
- **Optocoupler / opto-isolated** — an LED+sensor that passes a signal while
  electrically isolating two circuits (protects the MCU).
- **Active-LOW** — signal is "on" when the pin is at 0V (our driver wiring).
- **Potentiometer** — an adjustable resistor; the buck's voltage-set screw.
- **Multimeter** — the one tool to buy; measures voltage/continuity. Learn
  "measure DC volts" and "continuity beep" — that's 90% of debugging.

---

## 10. If you buy/borrow one tool

A **multimeter** (a $15 one is fine). Two things it does that will save you:
- **Measure DC voltage:** confirm your buck really outputs 5.0V before you plug
  in the servo. Confirm 12V is 12V.
- **Continuity (beep) mode:** touch two points; it beeps if they're connected.
  Use it to verify all your grounds are actually one node (section 3), and to
  catch shorts before powering on.

📺 Search `how to use a multimeter DroneBot` — 20 minutes, and you'll debug
hardware like you debug code.

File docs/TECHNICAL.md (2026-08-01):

# ECE180 Smart Trashbin — Recyclable & Household Waste Classification

Transfer-learning image classifier for a smart trashbin built on the **Arduino UNO Q**.
Inference and the camera loop run on the UNO Q's Qualcomm Dragonwing Linux MPU;
the companion STM32 MCU drives the sorting hardware (NEMA-17 stepper, optional
servo arm), reached from Linux over the Arduino **RouterBridge** RPC. The board
is **plug-and-play**: on power-up it auto-starts both the classifier and the
motor controller with no manual steps (see [On-Device Deployment](#on-device-deployment-uno-q--plug-and-play)).

**Course:** ECE 180, UC San Diego
**Dataset:** [Recyclable and Household Waste Classification](https://www.kaggle.com/datasets/alistairking/recyclable-and-household-waste-classification) (30 classes, ~15k images; each class has `default` studio and `real_world` cluttered subsets)

---

## Target Hardware — Arduino UNO Q

| Component | Spec |
|---|---|
| SoC | **Qualcomm Dragonwing QRB2210** |
| Inference compute | Quad-core **Cortex-A53** CPU + **Adreno 702** GPU |
| OS | Debian Linux (on the MPU side) |
| Real-time control | STM32U585 MCU (Zephyr), drives the stepper/servo; reached over RouterBridge |

The model runs on the Linux side. Two viable TFLite runtimes on this SoC:

- **int8 on CPU via XNNPACK** — fastest, smallest, minor accuracy trade-off
- **fp16 / fp32 on the Adreno GPU delegate** — near-zero accuracy loss

The notebook exports both int8 and float variants and **measures each one's real
accuracy**, so the deployment choice is data-driven.

---

## Approach

- **Model:** a single deployment target — **MobileNetV3-Large** (ImageNet-pretrained `IMAGENET1K_V2` weights), fine-tuned at **256×256** with a fresh 30-way head. There is no separate "reference" backbone: Large is the best accuracy/latency point that still runs int8 on the UNO Q, so it's the only model trained and shipped. (MobileNetV3-Small stays wired into `make_model` as a lighter fallback if the on-device latency proxy comes back too slow.)
- **Split:** stratified 70/15/15 by (class, subset) so `real_world` images are proportionally represented in val/test — reported metrics reflect what the trashbin camera actually sees.
- **Training:** two-stage fine-tune (head-only warmup → full fine-tune), AdamW + cosine schedule, label smoothing 0.1, mixed-precision (AMP), early stopping on val accuracy.
- **Accuracy techniques** (all training-time only — the exported model is a single plain network):
  - **EMA** of weights — the averaged model is checkpointed and deployed
  - **MixUp + CutMix** regularization
  - **Class-balanced sampling** across the 30 classes (helps macro-F1)
- **Augmentation:** camera-realistic — exposure/color jitter, Gaussian blur, random resized crop, random erasing — to close the studio→live-camera gap.
- **Evaluation:** test accuracy, macro-F1, 30×30 confusion matrix, and a **domain-shift check** reporting `default` vs. `real_world` accuracy separately.
- **Confidence calibration (Cell 12b):** temperature scaling fitted on val + a threshold sweep, so the clarification-loop threshold is a measured number, re-measured per exported int8/fp32 variant.
- **Export:** PyTorch → ONNX + three TFLite variants (fp32, dynamic-int8, static/per-channel int8), each with **measured on-test accuracy vs. the fp32 baseline**, plus `labels.txt` and a reference `classify_frame()` entry point for the RTOS→Linux handoff.

---

## Training Setup

Designed for **Google Colab** on a **T4 GPU runtime** (most compute-unit-efficient
for a model this size — a full run of MobileNetV3-Large is roughly **4–6 compute units**).

| Setting | Value |
|---|---|
| GPU | T4 (batch 48, 2 workers) |
| Resolution | 256×256 |
| Schedule | Stage 1: 3 epochs head-only · Stage 2: up to 30 epochs full fine-tune |
| Early stop | patience 6 (typically ends stage 2 around epoch 16–24) |
| Optimizer | AdamW, cosine LR, weight decay 1e-4, label smoothing 0.1 |

Cell 9 prints a **live compute-unit meter** (auto-detects the GPU and its Colab
billing rate) so you can watch cost accrue per epoch.

---

## Running

1. Set the runtime to **T4 GPU** (Runtime → Change runtime type).
2. Add Colab Secrets (🔑 sidebar), each with notebook access: `GITHUB_TOKEN`, `KAGGLE_USERNAME`, `KAGGLE_KEY`.
3. Run `ECE180_Complete_Notebook.ipynb` top to bottom. **Run the export cell (Cell 13) last** — `litert-torch` pins torch versions and its install can disturb the training environment.

The dataset downloads once via kagglehub into Google Drive
(`MyDrive/ECE180_project/`); checkpoints and results persist there too.
Training is **multi-session safe** — if Colab disconnects, re-run the notebook
and it resumes from the last epoch (including EMA state), skipping completed models.

## Repo Structure

```
.
├── ECE180_Complete_Notebook.ipynb   # Full pipeline: download → train → eval → export
├── deploy/                          # UNO Q runtime (see On-Device Deployment below)
│   ├── camera_loop.py               #   host: camera capture + classify + report + sort trigger
│   ├── infer_uno_q.py               #   host: TFLite inference matching eval_tf preprocessing
│   ├── bin_map.py                   #   host: label → bin index
│   ├── motor_bridge.py              #   host: POSTs target bin to the motor App (:8071)
│   ├── motor_cli.py                 #   laptop: manual motor control over ssh (standalone)
│   ├── clarification_client.py      #   host: low-confidence → webapp clarification queue
│   ├── edge_impulse_upload.py       #   reference: push corrected {image,label} to Edge Impulse
│   ├── motor_app/                   #   Arduino App Lab app that owns the MCU (motors)
│   │   ├── app.yaml                 #     app manifest (publishes command port 8071)
│   │   ├── sketch/sketch.ino        #     MCU: stepper + servo, Bridge.provide("sort"/"step"/…)
│   │   └── python/main.py           #     App: HTTP :8071 → Bridge.call(…)  (sort + manual)
│   ├── run_trashbin.sh              #   boot: classifier self-restart loop (@reboot cron)
│   ├── start_motor_app.sh           #   boot: waits for daemon, starts the motor App (@reboot cron)
│   ├── calibrate_round.sh           #   bench: sort into all four bins, check the pole returns to 0
│   └── move_both.sh                 #   bench: jog stepper + sweep servo, then undo it
├── webapp/                          # dashboard/clarification service (deployed to the droplet)
│   └── server.py                    #   Bin-ary Sort: FastAPI + SQLite, the deployed app
└── README.md
```

Drive layout (created by the notebook):

```
MyDrive/ECE180_project/
├── WasteDataset/      # 30 class dirs × {default, real_world}
├── checkpoints/       # *_best.pt, *_resume.pt, progress.json
├── results/           # metrics JSON + plots
└── export/            # ONNX / TFLite models + labels.txt
                       #   + quantization_report.json (per-variant acc, latency,
                       #     recommended confidence threshold)
                       #   + confidence_calibration.json (temperature + sweep)
```

## On-Device Deployment (UNO Q — plug-and-play)

The runtime is split across the UNO Q's two processors, wired so the board comes
up fully autonomous on power — no cable, no manual start.

```
                Linux MPU (Debian)                         STM32 MCU (Zephyr)
  ┌──────────────────────────────────────────┐        ┌───────────────────────┐
  │ camera_loop.py  (cron @reboot, self-loop) │        │ motor_app sketch.ino  │
  │   USB webcam → classify → report dashboard│        │   Bridge.provide(     │
  │   → motor_bridge.send_sort(bin)           │        │     "sort", …)        │
  │        │  HTTP POST :8071/sort            │        │   stepper 2/3/4       │
  │        ▼                                  │        └──────────▲────────────┘
  │ motor_app python/main.py  (App Lab app)   │  RouterBridge RPC │
  │   HTTP :8071 → Bridge.call("sort", bin) ──┼──(/run/arduino-router.sock)──┘
  └──────────────────────────────────────────┘
```

**Why an App for the motors.** On the UNO Q the STM32 is *not* a serial tty — it
is reachable only over the Arduino **RouterBridge** (RPC across an internal
link), and that bridge is only exposed inside an **Arduino App Lab** app. So
motor control lives in `deploy/motor_app/` (installed on the board as
`~/ArduinoApps/nema17`, display name *"Trashbin Motor"*). `arduino-app-cli app
start` compiles + flashes `sketch.ino` to the MCU and runs `python/main.py` in a
container; the app publishes an HTTP command port (`8071`) to the host.

**Rotation logic.** `sort(bin)` rotates the pole to the bin by the **shorter
direction** (clockwise or counter-clockwise); on an exact tie it goes
**clockwise**. The call blocks until the move finishes and returns the bin, so
the HTTP response doubles as the motion ack.

**Autostart (no root).** Installing a systemd service needs a sudo password, so
plug-and-play is instead two `@reboot` entries in the `arduino` user's crontab:

| Boot script | Role |
|---|---|
| `start_motor_app.sh` | waits for docker + the App Lab daemon, then `app start` the motor App |
| `run_trashbin.sh` | runs `camera_loop.py` in a self-restarting loop (relaunches on crash) |

The classifier runs with `MOTOR_ENABLED=1` and `MOTOR_URL=http://127.0.0.1:8071`;
if the motor App is down, sort calls are best-effort and never crash the loop.

**Calibration knobs** (top of `deploy/motor_app/sketch/sketch.ino`): the stepper
is on pins **PUL=2 / DIR=3 / ENA=4** (common-anode, active-LOW) at **1600
steps/rev** (1/8 microstep → 400 steps/bin, 4 bins). These must match the
driver's physical wiring — if they don't, sort RPCs still ack (`landed=N`) but
no pulses reach the driver and the pole never turns. If the pole turns the wrong
way, swap the `CW`/`CCW` constants; if it over/under-shoots a bin, rescale
`STEPS_PER_REV` to the driver's DIP microstep setting. The servo arm and homing
switch are left **off** until wired (`SERVO_ENABLED` / `HOMING_ENABLED`). After
any change:
`arduino-app-cli app restart ~/ArduinoApps/nema17`.

### Manual motor control over SSH

`deploy/motor_cli.py` drives both motors by hand from a laptop — standalone (it
imports nothing else in `deploy/`), it just `ssh`es to the board and `curl`s the
motor App. Full details in [`docs/MOTOR_CONTROL.md`](docs/MOTOR_CONTROL.md).

The big stepper is addressed by **absolute pulse position, 0–1600** (one full
revolution at the 1/8 microstep setting; bins sit at 0 / 400 / 800 / 1200), and
the servo arm by **absolute angle, 0–180**:

```bash
export MOTOR_SSH=arduino@uno-q.local   # or --ssh; add --port 2222 --jump root@<droplet> for the tunnel
python3 deploy/motor_cli.py step 800   # stepper -> pulse 800 (half turn, == bin 2)
python3 deploy/motor_cli.py nudge -25  # stepper -> 25 pulses counter-clockwise
python3 deploy/motor_cli.py servo 160  # arm -> 160 degrees
python3 deploy/motor_cli.py pos        # read position, move nothing
python3 deploy/motor_cli.py repl       # interactive: a bare 0-1600 is a position
```

Moves take the shorter way round and block until the motor stops, so the printed
result is the position the MCU actually reached. `servo` reports the peripheral
as disabled until `SERVO_ENABLED` is flipped in the sketch. This shares the
`:8071` App with the classifier, so the App must be running.

> **Python environment note:** the board's system Python is externally managed
> with no venv (the `python3.13-venv` apt package needs a password). The host
> classifier's deps (`ai-edge-litert`, `opencv-python-headless`, `numpy`,
> `pillow`, `requests`) are installed to the **user site**
> (`pip install --user --break-system-packages`), which is why `run_trashbin.sh`
> uses `/usr/bin/python3` with `PYTHONPATH` pointed at `~/.local`. The motor App
> gets its own environment from the App Lab runtime.

## Deployment Notes (UNO Q)

- The Linux-side inference code **must replicate the notebook's `eval_tf`
  preprocessing exactly**: resize shorter side to ~293 → center-crop 256 →
  ImageNet mean/std normalization. Preprocessing mismatch is the most common
  cause of "works in Colab, fails on device."
- Prefer the variant chosen from `export/quantization_report.json`: **dynamic-int8**
  is usually within a fraction of a percent of fp32 and runs on XNNPACK CPU;
  **static-int8** is fastest; fall back to **fp32 on the Adreno GPU delegate** if
  int8 accuracy is unacceptable.
- The static-int8 model is calibrated on `real_world` training images so its
  quantization ranges match the live camera domain.
- MobileNetV3-Large (~5.4M params) runs comfortably on the quad Cortex-A53 for a
  non-real-time per-drop workload; the
  export cell prints a CPU latency proxy (the A53 is ~2–4× slower than Colab CPU).

## Confidence-Gated Clarification Loop

Every classification carries a **temperature-scaled** softmax confidence score.
Below `CONFIDENCE_THRESHOLD` (calibrated in the notebook; env-configured on the
device, fallback 0.60), the device asks a human instead of guessing, and that
correction feeds back into the shared model:

```
UNO Q (deploy/infer_uno_q.py)
  classify frame -> (label, confidence)
  confidence < CONFIDENCE_THRESHOLD?
     -> deploy/clarification_client.py: POST frame + top-k to webapp,
        queue locally if offline (retried via flush_pending())
                    |
                    v
Webapp (separate repo/service) — notifies a human, they pick the right label,
webapp persists the correction
                    |
                    v
deploy/edge_impulse_upload.py — webapp backend calls this (or ports the
pattern into its own stack) to push the corrected {image, label} into the
shared Edge Impulse project's training data
                    |
                    v
Next retrain/export cycle -> updated .tflite -> redeployed to every bin
```

`deploy/` implements the device side end-to-end (TFLite inference matching
`eval_tf` preprocessing, thresholding, webhook client). The webapp and the
Edge Impulse-triggered retrain/redeploy job are out of this repo's scope —
`deploy/clarification_client.py`'s module docstring is the API contract the
webapp must implement (`POST /api/clarifications`), and
`deploy/edge_impulse_upload.py` is a reference the webapp backend can call
once a human confirms a label.

**Threshold calibration (measured, not guessed):** raw softmax from a
label-smoothed model isn't a calibrated probability, so the notebook calibrates
it. **Cell 12b** fits temperature scaling on the val set (argmax unchanged;
confidence becomes ≈ P(correct)), sweeps thresholds, and saves
`export/confidence_calibration.json`. **Cell 13** then re-measures the
recommended threshold **per TFLite variant** (int8 shifts logits) into
`quantization_report.json`. On the device, set both env vars for the variant
you ship — `TEMPERATURE` and `CONFIDENCE_THRESHOLD` — which
`deploy/infer_uno_q.py` reads; the defaults (T=1.0, 0.60) are only a fallback.
The selection rule is: lowest threshold whose auto-accepted predictions are
≥95% correct, which maximizes coverage (fewest human clarifications) at that
accuracy floor.

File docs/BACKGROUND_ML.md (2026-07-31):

# ECE180 Smart Trashbin — Study Notes

*Personal study notes for `ECE180_Complete_Notebook.ipynb`. Written to be readable
from zero — every concept is explained before it's used. Numbers quoted are from
the actual training run (see `results/` and `exports/`).*

---

## Table of Contents

1. [The problem and the hardware](#1-the-problem-and-the-hardware)
2. [The dataset and why splitting it correctly matters](#2-the-dataset-and-why-splitting-it-correctly-matters)
3. [Transfer learning — why we don't train from scratch](#3-transfer-learning--why-we-dont-train-from-scratch)
4. [Model choice: MobileNetV3-Large vs. the alternatives](#4-model-choice-mobilenetv3-large-vs-the-alternatives)
5. [Data augmentation — simulating a cheap camera](#5-data-augmentation--simulating-a-cheap-camera)
6. [The training recipe, hyperparameter by hyperparameter](#6-the-training-recipe-hyperparameter-by-hyperparameter)
7. [Colab survival engineering](#7-colab-survival-engineering)
8. [Evaluation — accuracy, macro-F1, confusion matrix, domain shift](#8-evaluation)
9. [Confidence calibration — temperature scaling and the threshold](#9-confidence-calibration)
10. [Quantization and export for the UNO Q](#10-quantization-and-export-for-the-uno-q)
11. [Deployment contract — what must match on the device](#11-deployment-contract)
12. [The design philosophy, and roads not taken](#12-design-philosophy-and-roads-not-taken)

---

## 1. The problem and the hardware

**Goal:** a trashbin that looks at the item someone is about to throw away and
classifies it into one of **30 waste categories** (aluminum cans, plastic water
bottles, cardboard boxes, food waste, glass jars, …) so it can route
recyclables vs. trash automatically.

**Hardware: Arduino UNO Q.** It's a dual-brain board:

| Chip | OS | Role |
|---|---|---|
| STM32 microcontroller | RTOS (real-time OS) | camera capture, motors/servos, timing-critical control |
| Qualcomm Dragonwing QRB2210 (4× ARM Cortex-A53 @ ~2 GHz + Adreno 702 GPU) | Debian Linux | runs the neural network |

The split exists because a Linux system can't make hard real-time guarantees
(the kernel might schedule something else at the wrong moment), while a
microcontroller can't run a modern CNN. So: RTOS grabs a frame → hands it to
Linux → Linux runs the classifier → answer goes back.

**Key deployment constraint to keep in mind through everything below:** the
Cortex-A53 is a small, in-order ARM core from ~2012's design lineage. It cannot
run desktop-sized models, and it's dramatically faster at 8-bit integer math
than 32-bit float math. But — critically — the bin only classifies **one frame
per item drop**, not a live video stream, so we have a *latency budget of
hundreds of milliseconds*, not tens. That single fact drives the model choice
(Section 4) and lets us prioritize accuracy over speed.

**The notebook** (`ECE180_Complete_Notebook.ipynb`) is the entire ML pipeline,
run top-to-bottom on Google Colab with a T4 GPU:

```
Cell 0-4   setup: clone repo, check GPU, mount Drive, download dataset, pip installs
Cell 5     manifest + stratified split + transforms
Cell 6     Dataset class + model factory
Cell 7     hyperparameter config
Cell 8     training helpers (checkpointing, EMA, MixUp, epoch loop)
Cell 9     the actual two-stage training run
Cell 10    test-set evaluation
Cell 11    confusion matrix + per-class F1
Cell 12    domain-shift check (default vs real_world)
Cell 12b   confidence calibration (temperature + threshold)
Cell 13    export: ONNX + fp32/dynamic-int8/static-int8 TFLite, each accuracy-measured
Cell 14    reference live-inference function
Cell 15    push metrics/reports back to GitHub
```

Every cell is **idempotent** — safe to re-run after a Colab disconnect
(Section 7 explains how).

---

## 2. The dataset and why splitting it correctly matters

**Dataset:** Kaggle's *Recyclable and Household Waste Classification* —
~15,000 images, 30 classes. Each class folder contains two subsets:

- `default/` — clean studio photos: object centered on a plain background,
  good lighting. Easy.
- `real_world/` — cluttered scenes, occlusion, weird angles, bad lighting.
  This is what the trashbin camera will actually see.

### The domain-shift problem

A model trained and tested on studio photos can score 95%+ and then fall apart
on a real camera feed. The mismatch between training-data distribution and
deployment-data distribution is called **domain shift**, and it is the single
most common way embedded-vision projects fail. This notebook attacks it in
three separate places:

1. **The split is stratified by (class, subset)** — so `real_world` images are
   proportionally present in validation and test. The reported metric
   therefore reflects deployment conditions, not just studio conditions.
2. **Augmentation simulates the camera** (Section 5).
3. **Quantization calibration uses `real_world` images** (Section 10).

### Train / validation / test — why three splits?

- **Train (70%)** — the model learns from these via gradient descent.
- **Validation (15%)** — used for *decisions during development*: when to
  early-stop, which epoch's weights are "best", fitting the temperature,
  choosing the confidence threshold. The model never trains on these, but our
  *choices* are fit to them, so val performance is slightly optimistic.
- **Test (15%)** — touched exactly once, at the end. Because no decision was
  ever made using it, its number is an unbiased estimate of real performance.

If you tune anything on the test set (even "just" a threshold), the test score
stops being trustworthy — you've leaked information. This is why Cell 12b
picks the threshold on **val** and only *verifies* it on test.

### How the split is built (Cell 5)

```python
def split_manifest(df, val_frac=0.15, test_frac=0.15):
    for _, g in df.groupby(['label', 'subset']):   # every (class, subset) group
        rng = np.random.RandomState(SEED)          # SEED = 42, deterministic
        rng.shuffle(idx)
        # first 15% → test, next 15% → val, rest → train
```

- **Stratified** = each of the 60 groups (30 classes × 2 subsets) is split in
  the same 70/15/15 ratio. Without stratification, random chance could put
  most of some rare class's `real_world` images in train and none in test.
- **Deterministic** = fixed seed means the same images land in the same split
  every session. This matters enormously for a multi-session Colab workflow —
  if the split changed between sessions, images trained on yesterday could
  appear in today's test set (leakage), and results wouldn't be comparable.

A **manifest DataFrame** (`filepath, label, class, subset`) is built by
walking the directory tree once; everything downstream indexes into it. This
is cleaner than torchvision's `ImageFolder` because we need the `subset`
column for stratification and the domain-shift evaluation.

---

## 3. Transfer learning — why we don't train from scratch

A CNN trained from random initialization needs to *discover* everything: what
an edge is, what texture is, what a curved metallic surface looks like.
ImageNet-scale training (1.28M images) is what it takes to learn those
general visual features well. With only ~10.5k training images across 30
classes (~350/class), a from-scratch CNN would either underfit (too small) or
memorize the training set (too big) — this is **overfitting**: great train
accuracy, poor test accuracy.

**Transfer learning** sidesteps this:

1. Take a network **pretrained on ImageNet**. Its early layers detect edges,
   colors, and textures; middle layers detect parts and materials; late layers
   detect object-like concepts. Almost all of that transfers to waste
   classification — a crushed can is still made of edges, gloss, and metal
   texture.
2. **Replace the head**: the final linear layer maps 1280 features → 1000
   ImageNet classes; we swap it for a fresh 1280 → 30 layer
   (`m.classifier[3] = nn.Linear(..., 30)`).
3. **Fine-tune**: continue training on our data, gently, so the pretrained
   features adapt without being destroyed.

The result: we get the benefit of 1.28M training images while only paying for
~10.5k of our own. This is *the* standard approach for small/medium vision
datasets and it's why the notebook reaches ~89% on a 30-way task in a few GPU
hours.

One free bonus: the notebook loads `IMAGENET1K_V2` weights for
MobileNetV3-Large. Same architecture as V1, but torchvision retrained it with
a modern recipe (longer schedule, better augmentation) — about **+1 pp**
ImageNet accuracy at zero cost to us.

---

## 4. Model choice: MobileNetV3-Large vs. the alternatives

The notebook trains **one** deployment model: `mobilenet_v3_large`,
ImageNet-pretrained, at **256×256** input. Here's the full reasoning, because
model choice is where most of the engineering judgment lives.

### What makes MobileNetV3 "mobile"?

Standard convolutions are expensive: a 3×3 conv with C_in input and C_out
output channels costs 9·C_in·C_out multiply-adds per pixel. MobileNets replace
these with **depthwise-separable convolutions**: a depthwise 3×3 (each channel
filtered independently, cost 9·C_in) followed by a pointwise 1×1 mixing
channels (cost C_in·C_out). That's roughly an 8–9× compute reduction per
layer. V3 adds:

- **Inverted residual blocks** (expand → depthwise → project) from V2,
- **Squeeze-and-Excite (SE) blocks** — a tiny attention mechanism that
  reweights channels,
- **hard-swish / hard-sigmoid activations** — piecewise-linear approximations
  of swish/sigmoid chosen specifically because they're cheap *and quantize
  cleanly to int8* (a real sigmoid's smooth curve is awkward to represent in
  8-bit fixed point; a piecewise-linear one is not),
- an architecture found partly by **neural architecture search (NAS)**
  optimizing directly for accuracy-vs-mobile-latency.

That last two points matter here: MobileNetV3 was *co-designed* for exactly
our deployment (int8 on ARM), so its quantization behavior is well-trodden and
predictable.

### The candidates

| Model | ImageNet top-1 | Params | Why / why not |
|---|---|---|---|
| **MobileNetV3-Small** | 67.7% | ~2.5M | 3–4 pp weaker features. Its speed advantage buys nothing here — the bin isn't real-time. Kept wired into `make_model` as a fallback if on-device latency surprises us. |
| **MobileNetV3-Large** ✅ | 75.2% (V2 weights ~76.2%) | ~5.4M (4.24M with the 30-class head) | Best accuracy that still runs comfortably int8 on a quad-A53. ~0.22 GFLOPs/frame. |
| **EfficientNet-B0** | ~77.7% | ~5.3M | ~1–2 pp more accurate, but ~2× the A53 latency, and its *smooth* swish + SE combination is notoriously finicky for **static** int8 quantization (bigger, less predictable accuracy drops). |
| **ResNet-50** | ~80% | 25.6M | 6× the parameters, far more FLOPs. Wrong weight class for this device. |
| **ViT / anything transformer** | high | 22M+ | Transformers need more data to fine-tune well, and tiny-ViT int8 support on LiteRT/XNNPACK is immature compared to CNNs. |

**The decision rule:** on a 30-class *fine-grained* task (many classes are
visually similar — e.g., different kinds of plastic), backbone quality shows
up directly in accuracy. Since latency is not the binding constraint,
choose the most accurate backbone that (a) fits the device and (b) quantizes
predictably. That's Large. EfficientNet-B0's ~1 pp edge isn't worth 2× latency
plus quantization risk; Small's speed isn't needed.

### Why 256×256 instead of the standard 224?

Small objects (bottle caps, cutlery, straws) and cluttered scenes benefit from
more pixels. Compute grows roughly with the square of resolution
(256² / 224² ≈ 1.31, so ~31% more), which the latency budget absorbs. The eval
resize keeps ImageNet's resize:crop ratio (`RESIZE_SIZE = round(256·256/224) =
293`): resize the short side to 293, center-crop 256. Keeping this ratio fixed
matters because the pretrained features were learned at a particular
object-to-frame scale.

---

## 5. Data augmentation — simulating a cheap camera

**Augmentation** = randomly perturbing training images each epoch so the model
never sees the exact same picture twice. It's a regularizer (fights
overfitting) and, done thoughtfully, a *domain-gap closer*: if training images
are randomly degraded in the same ways the deployment camera degrades images,
the live feed stops being out-of-distribution.

The training transform (Cell 5), line by line:

```python
transforms.RandomResizedCrop(256, scale=(0.6, 1.0))  # random zoom/crop
transforms.RandomHorizontalFlip()                     # mirror
transforms.RandomRotation(20)                         # ±20° tilt
transforms.ColorJitter(brightness=0.4, contrast=0.3,
                       saturation=0.3, hue=0.05)      # exposure/white-balance
transforms.RandomApply([GaussianBlur(5, (0.1, 2.0))], p=0.3)  # focus/motion blur
transforms.ToTensor()
transforms.Normalize(IMAGENET_MEAN, IMAGENET_STD)
transforms.RandomErasing(p=0.2)                       # random occlusion patch
```

The camera-realism mapping:

| Augmentation | Real-world failure it simulates |
|---|---|
| RandomResizedCrop (down to 60% scale) | item not centered, partially out of frame, variable distance |
| Rotation ±20° | items land at arbitrary angles |
| Strong brightness/contrast jitter | cheap sensor auto-exposure, shadows inside the bin |
| Hue/saturation jitter | wrong white balance under artificial light |
| Gaussian blur (30% of the time) | fixed-focus lens, motion blur mid-drop |
| RandomErasing | occlusion by other trash or the bin lid |

**Evaluation uses none of this** — just deterministic resize → center-crop →
normalize (`eval_tf`). Two reasons: metrics must be reproducible, and the
device will run this exact deterministic pipeline. (The `Normalize` values are
the ImageNet channel means/stds — mandatory because the pretrained backbone
expects inputs in that statistical range.)

---

## 6. The training recipe, hyperparameter by hyperparameter

### The two-stage schedule

**Stage 1 — head warmup (3 epochs, LR 1e-3, backbone frozen).**
The new 30-way head starts with random weights. If the whole network trained
immediately, the head's large, essentially random gradients would backpropagate
into and scramble the delicate pretrained features. So the backbone is frozen
(`requires_grad=False`) and only the head trains — cheap (few parameters, no
backbone gradients) and it doubles as a learning-rate warmup.

**Stage 2 — full fine-tune (up to 30 epochs, LR 1e-4, everything unfrozen).**
Now the head is sensible, so the whole network can adapt together — but at
10× lower LR, because pretrained weights need nudging, not rewriting. Too high
an LR here causes **catastrophic forgetting** (the backbone loses its ImageNet
knowledge faster than it learns waste features).

### Every knob in Cell 7, and its justification

| Knob | Value | What it does / why this value |
|---|---|---|
| `BATCH_SIZE` | 48 | Images per gradient step. Sized to fit Large @ 256px in a T4's ~15 GB VRAM with AMP on. Bigger batches train faster per epoch but need more memory; 48 is the T4 sweet spot. (A100 config: 160, but ~7× the Colab unit cost.) |
| Optimizer | **AdamW** | Adam adapts a per-parameter learning rate from gradient history — robust default for fine-tuning. The "W" = *decoupled* weight decay: in plain Adam, L2 penalty gets tangled with the adaptive scaling and under-regularizes; AdamW applies decay directly to weights, as intended. |
| `WEIGHT_DECAY` | 1e-4 | Shrinks weights toward zero each step — an overfitting brake. 1e-4 is the standard fine-tuning value; higher would fight the pretrained weights. |
| LR schedule | **CosineAnnealingLR** | LR follows a half-cosine from the initial value down to ~0 over the stage. Early: big steps to move fast. Late: tiny steps to settle into a good minimum. Smoother than step-drops, no extra hyperparameters. |
| `LABEL_SMOOTH` | 0.1 | Instead of target = [0,…,1,…,0], target = 0.903 on the true class and 0.0033 on each other. Discourages the network from pushing logits to extremes → less overconfidence, better generalization, measurably better calibration behavior. **Side effect:** raw softmax stops being a probability, which is exactly why Cell 12b (temperature scaling) exists. |
| `EARLY_STOP_PATIENCE` | 6 | Stop stage 2 if val accuracy hasn't improved for 6 consecutive epochs. Saves compute and prevents late-stage overfitting. Set slightly longer than you'd use for Small because Large keeps improving later into training. In practice runs end around epoch 16–24 of 30. |
| `USE_WEIGHTED_SAMPLER` | True | The 30 classes have unequal image counts. A **WeightedRandomSampler** draws each image with probability inversely proportional to its class frequency, so every batch is roughly class-balanced. Without it, gradient pressure favors common classes and rare-class F1 suffers — this knob directly targets **macro-F1**. |
| `USE_MIXUP` + `MIXUP_ALPHA=0.2`, `CUTMIX_ALPHA=1.0` | True | **MixUp**: blend two images pixel-wise (`x = λx₁ + (1−λ)x₂`) and blend their labels the same way. **CutMix**: paste a rectangular patch of image 2 onto image 1; label = area-weighted mix. Each batch randomly uses one or the other (`v2.RandomChoice`). Both force the model to learn features that survive weird composites — strong regularization, empirically worth ~0.5–1 pp on fine-grained tasks. The α values control the Beta distribution λ is drawn from; 0.2/1.0 are the standard published values. Training-time only — the deployed network is unchanged. |
| `EMA_DECAY` | 0.9995 | See below. |
| AMP (`torch.autocast` + `GradScaler`) | on | **Automatic Mixed Precision**: forward/backward run in fp16 where numerically safe, fp32 where not. ~2× throughput and ~half the activation memory on a T4, with no accuracy loss. `GradScaler` scales the loss up before backward so tiny fp16 gradients don't underflow to zero, then unscales before the optimizer step. |

### EMA — the deployed weights are an average

`ModelEMA` keeps a shadow copy of the model updated every step:

```
ema_weight ← 0.9995 · ema_weight + 0.0005 · current_weight
```

SGD-family training bounces around a loss valley; the **exponential moving
average** of the trajectory sits nearer the valley floor and consistently
generalizes a bit better (the same idea powers most modern training recipes).
Two implementation details worth noting:

- The EMA copy averages **floating-point buffers too** (BatchNorm running
  mean/var), and copies integer buffers verbatim — averaging BN stats is
  necessary for the EMA model to actually work standalone.
- **Validation and checkpointing use the EMA weights**, because that's what
  ships. Validating the raw weights but deploying the EMA (or vice versa)
  would mean selecting the "best epoch" with the wrong model.
- 0.9995 (vs a common 0.999) = a longer averaging horizon, matched to the
  longer Large training schedule.

The EMA weights are ordinary fp32 — they quantize exactly like any other
weights, so this costs nothing at deployment.

### The loss

`nn.CrossEntropyLoss(label_smoothing=0.1)` — cross-entropy measures how far
the predicted distribution is from the target. Conveniently, PyTorch's
implementation accepts **either** integer class labels **or** soft
probability targets, so the same criterion handles normal batches and
MixUp/CutMix batches. Note the accuracy metric always compares against the
*hard* label (`y_hard` kept before mixup), since "accuracy against a blended
label" isn't meaningful.

### Compute budgeting (a Colab-specific concern)

Colab Pro bills in compute units: T4 ≈ 1.8 units/hr, A100 ≈ 13 units/hr. The
run targets a T4: ~2–3.5 hours ≈ 4–6 units for the full train. Cell 9 even
tracks a live `units_spent` estimate. The strategy is explicitly **one model,
trained well** rather than a zoo of half-trained models — for a fixed budget,
depth beats breadth when you already know the deployment target.

---

## 7. Colab survival engineering

Colab sessions die: idle timeouts, GPU reclaims, browser crashes. The notebook
treats disconnection as normal, not exceptional:

- **Atomic checkpoint writes** (`safe_torch_save`): write to `file.tmp`, copy
  the previous version to `file.bak`, then `os.replace(tmp, file)` —
  `os.replace` is atomic, so a crash mid-write can never leave a half-written
  checkpoint as the only copy. `safe_torch_load` falls back to `.bak` if the
  main file is corrupt.
- **Resume checkpoints**: every epoch saves `_resume.pt` containing model
  weights, EMA weights, current stage, epoch, best accuracy, and
  early-stopping counter. Re-running Cell 9 picks up exactly where it died —
  including **fast-forwarding the cosine scheduler** to the right epoch
  (otherwise the LR would restart too high and damage converged weights).
- **`progress.json`** marks the model as completed, so re-running the training
  cell after success is a no-op skip.
- **Best checkpoint separate from resume checkpoint**: `_best.pt` holds the
  EMA weights of the best-val-accuracy epoch (what we deploy); `_resume.pt`
  holds the latest raw state (what we continue from). These are different
  things and conflating them is a classic bug.
- **Dataset marker file** (`.complete`): the Kaggle download + copy-to-Drive
  only happens once; a partial copy from an earlier crash is detected and
  wiped before recopying.
- All heavy artifacts live on **Google Drive** (persists across sessions), not
  Colab's ephemeral `/content` disk.

---## 8. Evaluation

### Headline results (from `results/test_results.json`)

| Metric | Value |
|---|---|
| Test accuracy | **89.08%** |
| Macro-F1 | **0.890** |
| Parameters | 4.24M |

### Why report macro-F1 and not just accuracy?

- **Accuracy** = fraction of correct predictions. With imbalanced classes it
  can hide disasters: a model that's great on the 5 biggest classes and
  useless on 10 small ones can still post high accuracy.
- **F1** per class = harmonic mean of precision (of the times we said class X,
  how often were we right?) and recall (of the true class-X items, how many
  did we catch?).
- **Macro-F1** = the unweighted mean of the 30 per-class F1 scores — every
  class counts equally, so neglected rare classes drag it down visibly.

Here macro-F1 (0.890) ≈ accuracy (0.891), which tells us performance is
*even across classes* — the weighted sampler did its job.

### Confusion matrix (Cell 11)

A 30×30 grid: rows = true class, columns = predicted class, **row-normalized**
so each row shows "when the item was truly X, what did the model say?"
independent of class size. The diagonal is correct predictions; bright
off-diagonal cells reveal *systematic* confusions (e.g., visually similar
plastic categories). Cell 11 also prints the 10 weakest classes by F1 — the
actionable output: those are the classes to collect more data for, or to merge
if the downstream sorting decision doesn't distinguish them anyway.

### Domain-shift check (Cell 12) — the honest number

Test accuracy split by subset (`results/domain_shift.json`):

| Subset | Accuracy |
|---|---|
| `default` (studio) | 89.21% |
| `real_world` (cluttered) | **88.95%** |
| Gap | **+0.26 pp** |

This is arguably the most important result in the project. A typical
studio-trained classifier drops 5–15 pp on real-world imagery. A 0.26 pp gap
means the camera-realistic augmentation + stratified splitting essentially
closed the domain gap: **the model is as good on deployment-like images as on
easy ones**, and 88.95% is the number to quote for expected live performance.

---

## 9. Confidence calibration

### The problem

The trashbin has a **clarification loop**: when the model isn't sure, the
device asks the user ("is this recyclable?") instead of silently mis-sorting.
That requires a confidence threshold. Naively you'd use `max(softmax)` and a
hand-picked cutoff like 0.6. Two things are wrong with that:

1. **Softmax confidence is not a probability of being correct.** Modern
   networks are systematically miscalibrated, and label smoothing (which we
   used) distorts it further — in our case toward *under*confidence.
2. **A hand-picked threshold has no guarantee attached.** "0.6" means nothing
   until you measure what accuracy the accepted predictions actually achieve.

### Step 1 — Temperature scaling

**Temperature scaling** divides the logits by a single scalar T before
softmax: `probs = softmax(logits / T)`.

- T > 1 softens the distribution (less confident);
- T < 1 sharpens it (more confident);
- **argmax never changes** — the ranking of classes is invariant to a positive
  scalar divide. So calibration cannot hurt accuracy; it only fixes the
  *meaning* of the confidence number.

T is fitted on the **validation** set by grid search over [0.5, 5.0] in steps
of 0.05, minimizing **NLL** (negative log-likelihood = cross-entropy of the
scaled probabilities against true labels — the standard calibration
objective). One parameter fitted on ~2,280 points can't overfit.

**Fitted result: T = 0.55.** T < 1 means the raw model was *under*confident —
exactly the expected fingerprint of label smoothing (it trained the network to
never output extreme probabilities). Dividing by 0.55 re-sharpens the outputs
so that "0.8 confidence" once again means ≈80% chance of being right.

### Step 2 — Threshold sweep

With calibrated confidences, sweep thresholds t from 0.30 to 0.95 on the val
set and compute, for each:

- **coverage** = fraction of items with confidence ≥ t (auto-handled, no human);
- **accepted-accuracy** = accuracy on just those items.

There's an inherent trade: raise the threshold → accepted predictions get more
accurate, but you bug the human more often.

### Step 3 — Pick by target, verify on test

Decision rule: *the lowest threshold whose val accepted-accuracy ≥ 95%*
(`TARGET_ACCEPT_ACC = 0.95`). Lowest, because among all thresholds meeting the
accuracy guarantee, the lowest one maximizes coverage (fewest human
interruptions).

**Result: threshold = 0.80.** Verified on the untouched test set
(`exports/confidence_calibration.json`):

| Test-set check @ 0.80 | Value |
|---|---|
| Coverage (auto-handled) | 83.3% |
| Accepted-accuracy | **95.7%** ✓ (target ≥95%) |
| Clarification rate | 16.7% |

Translation for the product: the bin sorts ~5 of every 6 items automatically
and is right 95.7% of the time when it does; for the other ~1 in 6 it asks.
That's a *measured guarantee*, not a vibe.

One more subtlety handled in Cell 13: **quantization perturbs logits**, so the
threshold is re-measured per exported model variant (Section 10) — the shipped
variant uses *its own* threshold, not the fp32 one.

---

## 10. Quantization and export for the UNO Q

### What quantization is

Training produces **fp32** weights (32-bit floats). **Quantization** maps them
(and optionally the activations flowing between layers) to **int8**: pick a
scale s and zero-point z per tensor (or per channel) such that
`real ≈ s · (int8_value − z)`. Benefits on an ARM CPU:

- **~4× smaller** model (8 bits vs 32),
- **much faster** — A53-class cores have SIMD int8 dot-product paths (via the
  XNNPACK kernel library) that vastly outrun their float units,
- lower power.

Cost: rounding error in weights and activations → some accuracy drop. The
size of the drop depends on the architecture (Section 4: MobileNetV3 was
designed to keep it small) and on the quantization flavor.

### The three flavors, and the four exports

| Variant | Weights | Activations | Needs calibration data? | Runtime on UNO Q |
|---|---|---|---|---|
| fp32 `.tflite` | float | float | no | **Adreno 702 GPU delegate** (or CPU, slower) |
| **dynamic int8** | int8 | float (quantized on the fly per batch) | no | XNNPACK CPU |
| **static int8** (per-channel) | int8 | int8 with *fixed, pre-computed* ranges | **yes** | XNNPACK CPU — fastest |
| ONNX fp32 | float | float | no | portable fallback for other toolchains (onnx2tf, onnxruntime) |

- *Dynamic* quantization computes activation ranges at inference time —
  no calibration needed, accuracy near fp32, but the range computation adds
  overhead.
- *Static* quantization fixes activation ranges ahead of time by running
  **calibration data** through the prepared model and recording observed
  min/max per tensor. Fastest at inference, but if calibration data doesn't
  match deployment data, the ranges clip real activations and accuracy craters.
- *Per-channel* = each output channel of a conv gets its own scale, instead of
  one scale per whole tensor. Nearly free, and it substantially reduces weight
  quantization error — always use it.

**Calibration set choice — the domain-shift theme again:** ~10 images per
class, drawn from the **`real_world`** subset of the *training* split
(never val/test — that would leak). The int8 activation ranges are thereby
fitted to cluttered-camera statistics, i.e., what the bin actually sees.

### The export pipeline (modern PyTorch → TFLite path)

```
torch.export.export(model)                 # capture the graph (PT2, torch ≥2.6)
  → prepare_pt2e(captured, quantizer)      # insert observers (torchao PT2E API)
  → run calibration batches through it     # observers record ranges
  → convert_pt2e(...)                      # bake in quant/dequant ops
  → litert_torch.convert(...).export(path) # lower to a .tflite flatbuffer
```

(`litert-torch` is the renamed `ai-edge-torch`; LiteRT is the renamed
TensorFlow Lite.) The ONNX export uses the classic TorchScript exporter
(`dynamo=False`, opset 17) because it's the most robust across torch versions.

### Measured results (`exports/quantization_report.json`)

The critical engineering practice here: **never assume the quantization drop —
measure it.** Every variant is evaluated on the full 2,280-image test set
through the actual TFLite interpreter (4 threads, matching the quad A53), and
each gets its own re-measured confidence threshold:

| Variant | Test acc | Δ vs fp32 | Size | Threshold | Coverage @ ≥95% accept-acc |
|---|---|---|---|---|---|
| PyTorch fp32 (reference) | 89.08% | — | — | 0.80 | 83.3% |
| fp32 TFLite | **89.08%** | 0.00 pp | 17.1 MB | 0.75 | 85.5% |
| dynamic int8 | 87.37% | −1.71 pp | 4.6 MB | 0.55 | 79.8% |
| static int8 | 86.36% | −2.72 pp | 4.9 MB | 0.80 | 79.3% |

(Latency numbers in the report are Colab-CPU proxies — useful for *relative*
comparison only; real numbers must be measured on the A53.)

Notice how much the per-variant threshold matters: dynamic int8's calibrated
threshold is 0.55 while static int8's is 0.80 — quantization noise reshapes
the confidence distribution differently per variant. Shipping the fp32
threshold with an int8 model would silently break the 95% guarantee.

**The open deployment decision this data surfaces:** static int8 costs 2.7 pp
of accuracy for CPU speed we may not need. Since the bin is not
latency-bound, the fp32 TFLite on the **Adreno GPU delegate** (zero accuracy
loss) is worth benchmarking on-device before defaulting to int8. The whole
point of exporting four measured variants is that this choice is now
data-driven, not assumed.

---

## 11. Deployment contract

Cell 14 gives the reference `classify_frame(pil_image) → [(class, prob), …]`
function. The device-side implementation (`deploy/infer_uno_q.py`) must match
the notebook **exactly** on four things, or the accuracy and calibration
numbers become fiction:

1. **Preprocessing** = `eval_tf` precisely: resize short side to 293 →
   center-crop 256 → scale to [0,1] → normalize with ImageNet mean/std,
   RGB channel order. (Off-by-one in resize, BGR vs RGB, or skipping
   normalization are the classic silent killers.)
2. **Label order** = the sorted class list (`exports/labels.txt`). Index 7 in
   the logits must mean the same class on device as in training.
3. **Temperature division** — confidence must be computed as
   `softmax(logits / T)` with T = 0.55, or the threshold is meaningless.
4. **The variant-specific threshold** from `quantization_report.json` for the
   variant actually shipped.

Cell 15 pushes the small artifacts (metrics JSONs, confusion matrix PNG,
labels, calibration + quantization reports) to GitHub; the multi-MB
`.tflite`/`.onnx` binaries stay in Drive (and are gitignored).

---

## 12. Design philosophy, and roads not taken

Every choice in the notebook follows one principle: **optimize for the number
the deployed device achieves, not the number the notebook prints.**

| Decision | Deployment-first reasoning |
|---|---|
| Stratify split by (class, subset) | test score reflects the camera's world |
| Camera-realistic augmentation | closed the domain gap to 0.26 pp |
| MobileNetV3-Large over Small/EfficientNet | most accuracy that fits + quantizes predictably; latency budget says speed is not the constraint |
| Validate/deploy the EMA weights | select the model you actually ship |
| Calibrate confidence, threshold-by-target | "asks a human" has a measured ≥95% guarantee |
| Export 4 variants, measure each, per-variant thresholds | fp32-vs-int8 is decided by data, per-device benchmarking |
| One model trained well, not a model zoo | fixed compute budget → depth over breadth when the target is known |

**Roads not taken, and why:**

- *Training in int8 (quantization-aware training, QAT)* — would recover some
  of the 2.7 pp static-int8 drop, but adds significant training complexity;
  post-training quantization (PTQ) was tried first because it's cheap, and the
  fp32-on-GPU-delegate option may make the question moot.
- *Knowledge distillation from a big teacher* — could add ~1 pp, but needs a
  second (large) model trained first; poor fit for the compute budget.
- *Test-time augmentation / ensembling* — accuracy for multiple inference
  passes per frame; unattractive on-device even with a loose latency budget,
  and it complicates calibration.
- *A 2-way or 5-way "material group" head* — the sorting decision may not need
  30 classes; collapsing classes would raise accuracy substantially. Kept
  30-way because per-class granularity aids analysis, and grouping can happen
  *after* the argmax in device logic without retraining.

### Quick-reference card

```
Task        30-class waste classification, Kaggle dataset (~15k images)
Model       MobileNetV3-Large, IMAGENET1K_V2 pretrained, 256×256 input, 4.24M params
Training    2-stage: 3 ep head-only @1e-3 → ≤30 ep full @1e-4, AdamW, cosine LR,
            wd 1e-4, label smoothing 0.1, batch 48, AMP, early stop (patience 6)
Tricks      weighted sampler, MixUp(0.2)+CutMix(1.0), EMA 0.9995 (deployed)
Results     test acc 89.08%, macro-F1 0.890, domain gap +0.26 pp (rw 88.95%)
Calibration T = 0.55, threshold 0.80 → 83% coverage @ 95.7% accepted-accuracy
Export      fp32 TFLite 89.08% / dyn-int8 87.37% / static-int8 86.36%,
            per-variant thresholds 0.75 / 0.55 / 0.80
Target      UNO Q: 4×Cortex-A53 (XNNPACK int8) or Adreno 702 (fp32 delegate)
```

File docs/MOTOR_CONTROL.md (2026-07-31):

# Manual Motor Control — file map

How a manual motor command travels from a laptop to the two motors on the UNO Q,
and which file owns each hop. (For the automatic classifier path see the README's
architecture section; it enters at the same `:8071` port via `motor_bridge.py`.)

```
laptop                                board (UNO Q, Linux side)        MCU (STM32)
──────                                ─────────────────────────        ───────────
motor_cli.py  ──ssh + curl──►  motor_app/python/main.py  ──Bridge.call──►  motor_app/sketch/sketch.ino
  step 800                       POST /step {"step":800}                    rpcStep(800)
                                                                             └─ gotoStep() → pulses on PUL/DIR
```

## Files

| File | Role |
| --- | --- |
| `motor_cli.py` | **Standalone** host CLI. Builds an `ssh … curl` command, validates ranges locally, prints where the motor landed. Imports nothing else in `deploy/`. |
| `motor_app/python/main.py` | The App's HTTP layer on the board. One route per motor action; serializes everything behind `_lock` and forwards to the MCU over the RouterBridge. |
| `motor_app/sketch/sketch.ino` | MCU firmware. Owns `currentStep` (absolute pulse position) and the servo angle; exposes the RPCs below. |
| `motor_bridge.py` | The *classifier's* client for the same port (`/sort` only). Untouched by manual control. |
| `tests/test_motor_cli.py` | CLI tests — ssh/curl command shape, range rejection, REPL parsing. No board needed. |
| `tests/test_motor_app.py` | Board-side handler tests against a stubbed `arduino.app_utils`. |

## Command surface

| CLI | HTTP | RPC | Motor | Range |
| --- | --- | --- | --- | --- |
| `step N` / bare `N` in the REPL | `POST /step {"step":N}` | `step` | stepper (LM/big) | `0..1600` absolute pulses |
| `nudge ±N` / `+N`, `-N` in the REPL | `POST /nudge {"delta":N}` | `nudge` | stepper | `±1600` relative |
| `bin N` | `POST /step` at `N*400` | `step` | stepper | `0..3` |
| `sort N` | `POST /sort {"bin":N}` | `sort` | stepper (+ arm sweep) | `0..3` |
| `servo N` | `POST /servo {"angle":N}` | `servo` | servo arm | `0..180` degrees |
| `home` | `POST /home` | `home` | stepper | — |
| `zero` | `POST /zero {}` | `zero` | stepper | — |
| `release [0\|1]` | `POST /release {"on":N}` | `release` | stepper | bare = drop torque |
| `pos` | `GET /pos` | `pos` | stepper | read-only |
| `health` | `GET /health` | — | — | liveness |

## Geometry (keep these three in sync)

`STEPS_PER_REV = 1600` appears in `sketch.ino` (source of truth, set by the
TB6600 DIP microstep setting), `motor_app/python/main.py` (range check), and
`motor_cli.py` (range check + the `describe()` gloss). Four bins ⇒ 400 pulses
apart: bin 0 = step 0, bin 1 = 400, bin 2 = 800, bin 3 = 1200.

`currentStep` in the sketch is the single source of truth for position — bin
moves are just step moves at multiples of 400, so manual jogging and automatic
sorting can never disagree about where the pole is. Every move takes the shorter
way around the circle; an exact tie goes clockwise.

## Notes

- The servo arm is **enabled** (`#define SERVO_ENABLED 1`, 2026-07-30). Pin 6
  (chosen to stay clear of stepper 2/3/4 and the home switch on 5),
  `ARM_REST=160` / `ARM_SWEEP=0` — the arm parks at 160 and sweeps down to 0.
  Verified live: `POST /servo {"angle":160}` returns `landed=160` (it returned
  `-1` while compiled out).
  - Flipping that define is *not* sufficient on its own: `Servo.h` is not
    bundled with the `arduino:zephyr` core, so `sketch/sketch.yaml` must list
    `Servo (1.3.0)` under `libraries:` or the build dies with "Servo.h: No such
    file or directory" — and a failed build leaves the App **stopped**.
  - Note the param name differs by layer: HTTP takes `{"angle": N}`, the MCU
    RPC takes `deg`. `POST /servo {"deg":N}` fails with `bad request: 'angle'`.
  - **`rpcSort()` calls `sweepArm()`**, so with the servo on, every production
    sort now sweeps the arm and costs an extra `2*SWEEP_MS` (1 s). Decouple
    these if the arm should only move on manual command.
- Manual control needs the *"Trashbin Motor"* App running on the board — the
  same App the classifier needs (`start_motor_app.sh` starts it at boot).
- After editing the sketch:
  `arduino-app-cli app restart ~/ArduinoApps/nema17`.
- SSH target comes from `--ssh` / `$MOTOR_SSH` (default `arduino@uno-q.local`).
  Through the droplet's reverse tunnel: `--ssh arduino@localhost --port 2222
  --jump root@<droplet>`.
- **Manual zeroing (2026-07-30).** There is no homing switch wired, so
  `HOMING_ENABLED` stays `false` and nothing moves at boot — `homePole()` only
  declares `currentStep = 0`. The pole is returned to physical zero **by hand
  after every boot**, which makes that declaration true. Two RPCs support this:
  - `POST /release {"on":0}` — drops `ENA`, so the pole turns freely by hand
    instead of fighting holding torque (which skips steps). Position is *not*
    tracked while released. Any move re-energizes automatically (`rotate()`
    re-asserts `ENA` + 50 ms settle); `{"on":1}` does it explicitly.
  - `POST /zero {}` — declares the current physical spot step 0 / bin 0.
  Do this after **reflashes and `app restart` too**, not just power-on: those
  reset the MCU counter while the pole stays physically put.
  - Servo signal is on **D6** (was D9). **Working as of 2026-07-30**, verified
    on the bench. Three things were wrong at once:
    - *Overheating.* The sketch attached at boot and never detached, so pulses
      went out forever and a blocked or over-driven horn sat stalled at full
      current until it cooked. `setArmAngle()` now attaches, writes, waits
      `SERVO_TRAVEL_MS` (400 ms) for travel, then **detaches** — the arm is
      unpowered at rest. (Pulling the signal wire by hand was the same fix.)
      Consequence: the arm does not hold against a load between moves.
    - *Half travel.* `attach()` used the library's default pulse range; the
      horn swept ~half the commanded degrees. Range is now pinned to
      `SERVO_MIN_US`/`SERVO_MAX_US` = **600..2400 us**, giving full travel.
    - *Geometry.* Rest/sweep is **160 -> 0 -> 160** (`ARM_REST` 160 is the
      parked position), dwelling `SWEEP_MS` = **3 s** out. Swapping that pair
      is the only way to reverse the sweep; there is no direction flag.
    Note `landed` still echoes the commanded angle and is never proof of motion.
- **Sort returns the pole (2026-07-30).** `rpcSort()` records `currentStep`,
  goes out to the bin, sweeps, then returns to that starting position, so the
  platform is back at its loading spot for the next item. A full `sort` costs
  ~11 s: travel out + 0.4 s arm + 3 s dwell + 0.4 s arm + travel back.
- **Motion ramp (2026-07-30).** `rotate()` runs a trapezoidal profile:
  `PULSE_START_US` (2500) -> `PULSE_US` cruise (800) over `RAMP_STEPS` (120),
  decelerating symmetrically. Before this, moves started instantly at the full
  625 pulses/s — above the motor's pull-in rate. A 400-pulse bin move went from
  ~0.71 s to ~1.15 s; the slower travel is *wanted*, it stops the load being
  thrown. Short moves never reach cruise (ramp index clamps to the nearer end).
  The stutter that prompted this turned out to be the casing, not firmware.
- **Board firmware sync (2026-07-30).** `~/ArduinoApps/nema17` on the board was
  stale (Jul 23–24, pre-`f8bc323`): it had only `sort`/`goto`/`home`, so every
  manual RPC 404'd. `sketch.ino`, `python/main.py` and `app.yaml` were pushed
  from `deploy/motor_app/` and the App restarted (reflashes the STM32U5).
  Previous versions kept alongside as `*.bak-2026-07-30`. Verify a sync with
  `curl -s :8071/pos` on the board — `{"error": "not found"}` means stale.
- **SSH over Tailscale (primary).** The board runs `tailscaled` (Debian trixie
  arm64 package, `systemctl enable`d) as tailnet node **`uno-q` /
  100.119.45.76**. `ssh unoq` works from anywhere, key-based, and sidesteps the
  campus wifi's client isolation. The `unoq` / `unoq-usb` aliases live in
  `~/.ssh/config` on the laptop. Node key expires 2027-01-26 unless key expiry
  is disabled for the node in the Tailscale admin console.
- **SSH over USB (ADB, fallback).** On a network with client isolation (e.g. campus guest
  wifi) the board is unreachable by IP even when both are on the same subnet.
  App Lab talks to the board over ADB, and so can we — forward the board's sshd
  to a local port and SSH through USB:

  ```bash
  ~/.arduino15/packages/arduino/tools/adb/*/adb forward tcp:2222 tcp:22
  ssh unoq          # ~/.ssh/config alias -> arduino@127.0.0.1:2222
  ```

  The forward is per-`adb-server` and is lost when the board is unplugged or the
  server dies; re-run the `adb forward` line. With this, the CLI works as
  `MOTOR_SSH=arduino@127.0.0.1 MOTOR_SSH_PORT=2222 python3 deploy/motor_cli.py pos`.
  Board hostname is `cohua`, user `arduino`, ADB serial `2723903952`.

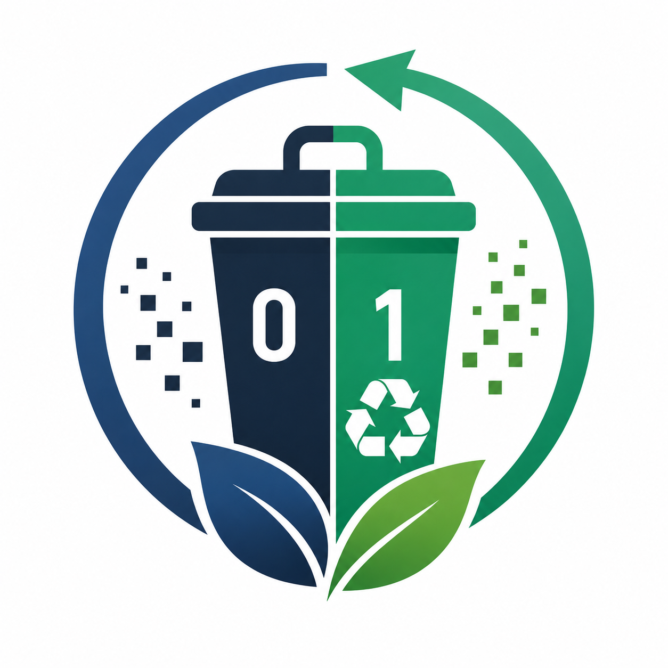
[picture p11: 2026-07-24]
webapp/Binsort.png

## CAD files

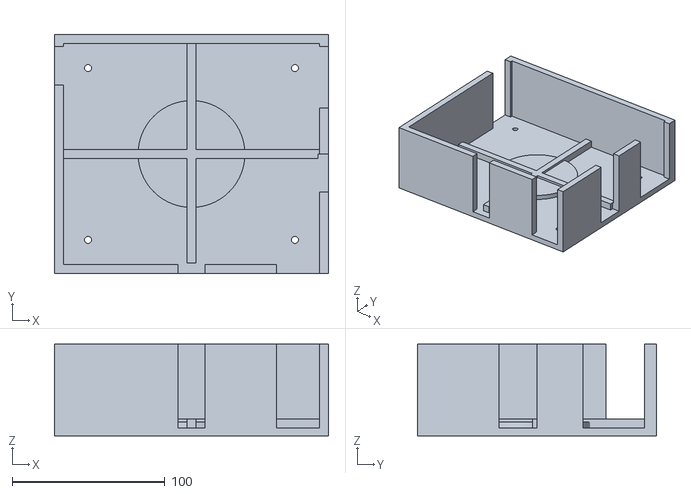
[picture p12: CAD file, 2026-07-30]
STL/Component_lid.stl
179.6 x 156.6 x 60.0

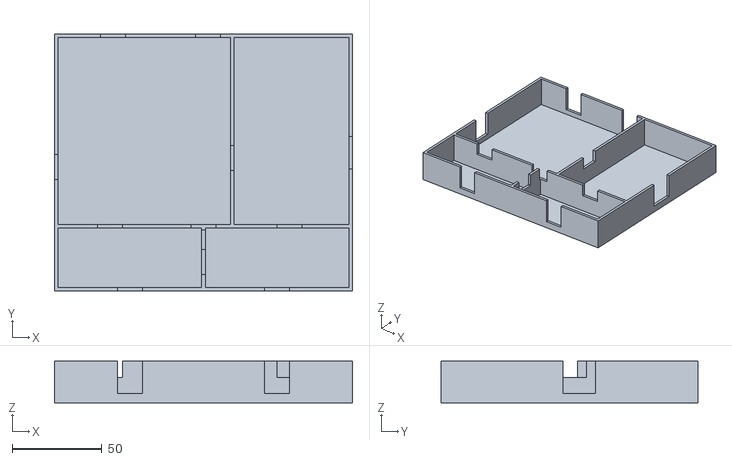
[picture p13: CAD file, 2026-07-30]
STL/Component_tray.stl
166.0 x 143.0 x 23.2

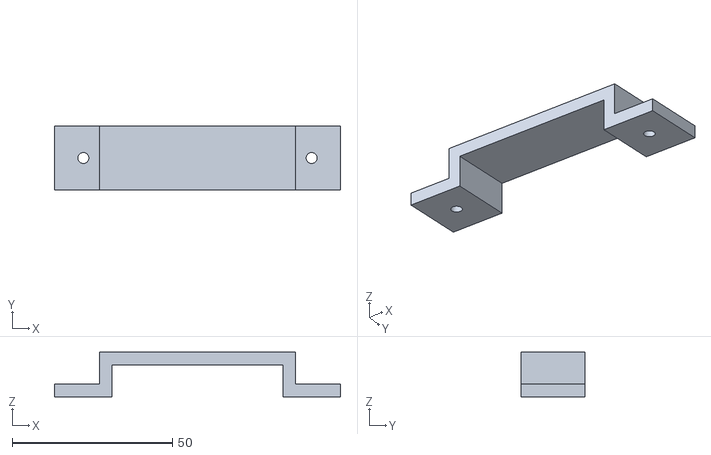
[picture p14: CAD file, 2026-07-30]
STL/Camera_securer.stl
89.2 x 20.0 x 14.0

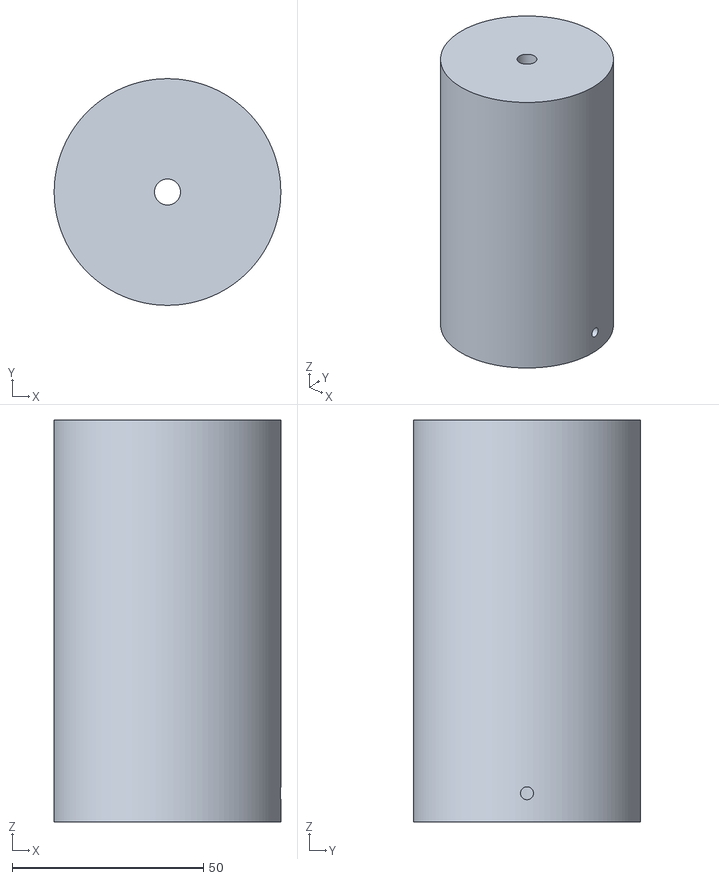
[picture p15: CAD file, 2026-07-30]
STL/Camera_mount.stl
59.2 x 59.2 x 105.0

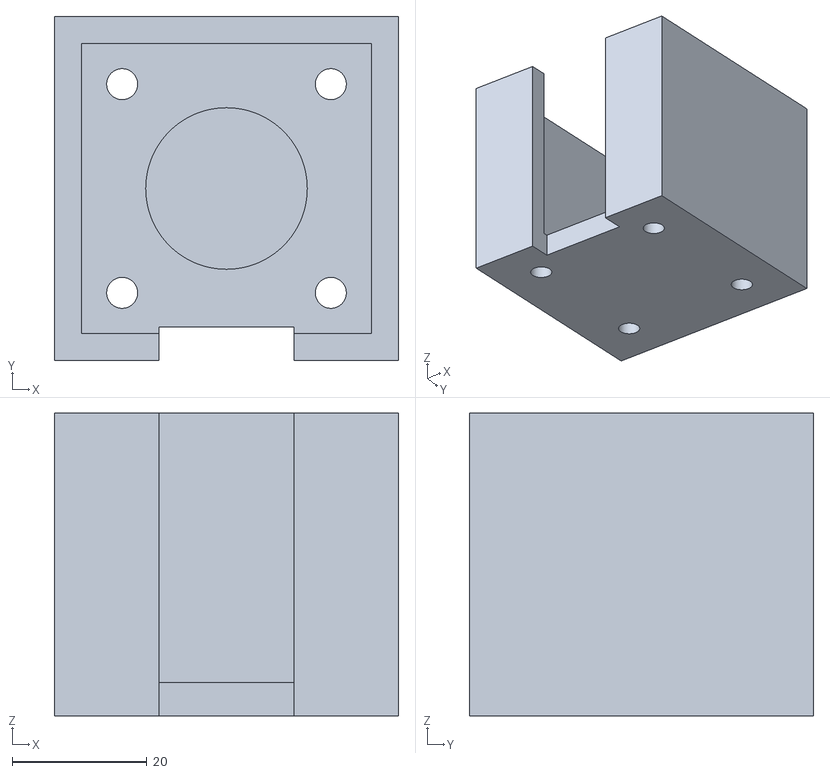
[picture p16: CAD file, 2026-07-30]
STL/Nema_holder.stl
51.1 x 51.1 x 45.0

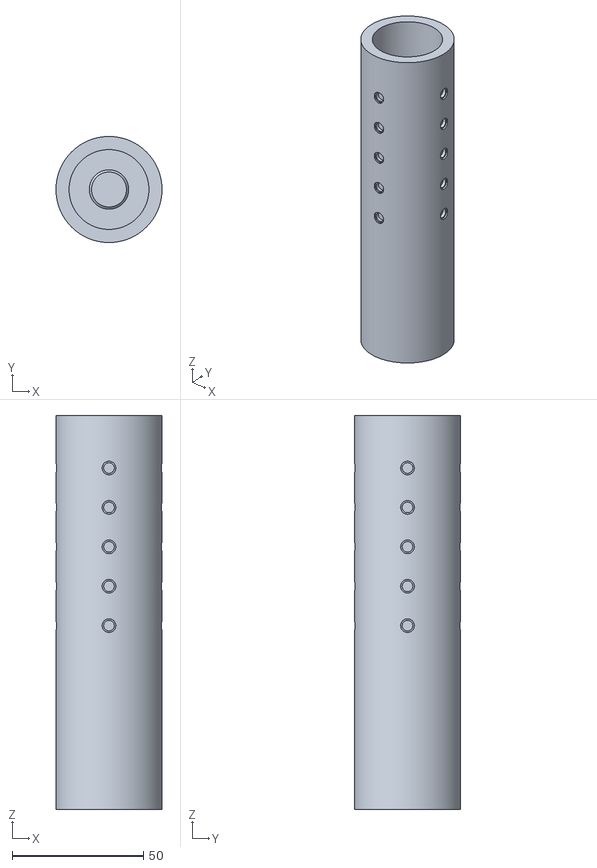
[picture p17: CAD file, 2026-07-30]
STL/Bottom_column.stl
40.4 x 40.4 x 150.0

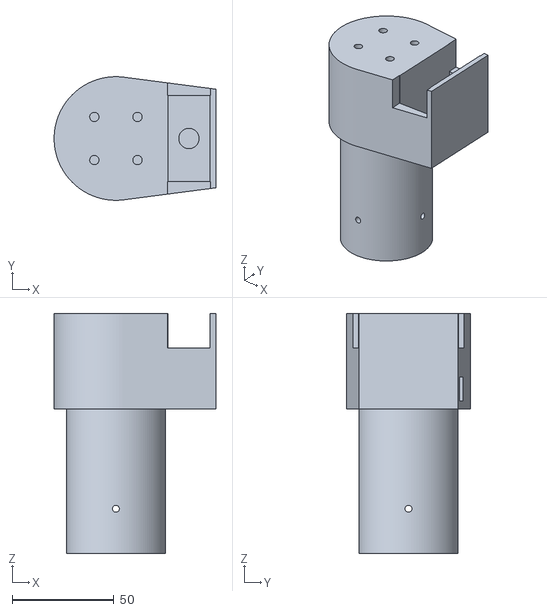
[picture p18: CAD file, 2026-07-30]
STL/Servo_holder.stl
79.6 x 60.8 x 118.0

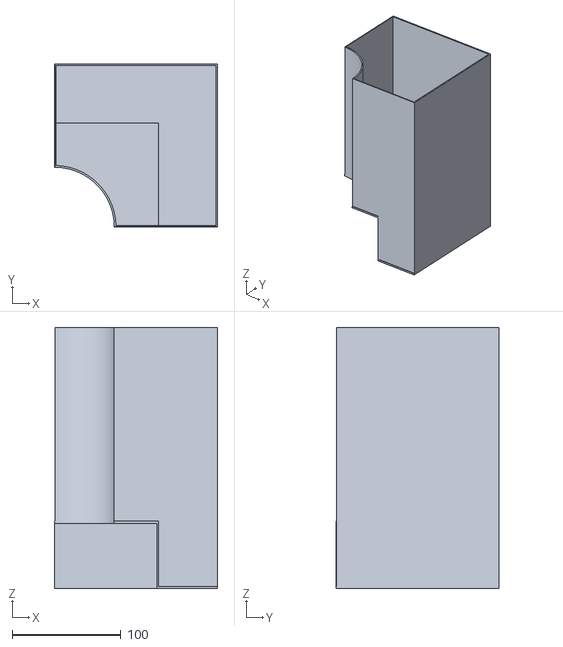
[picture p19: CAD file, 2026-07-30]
STL/Trash_bins.stl
150.0 x 150.0 x 240.0

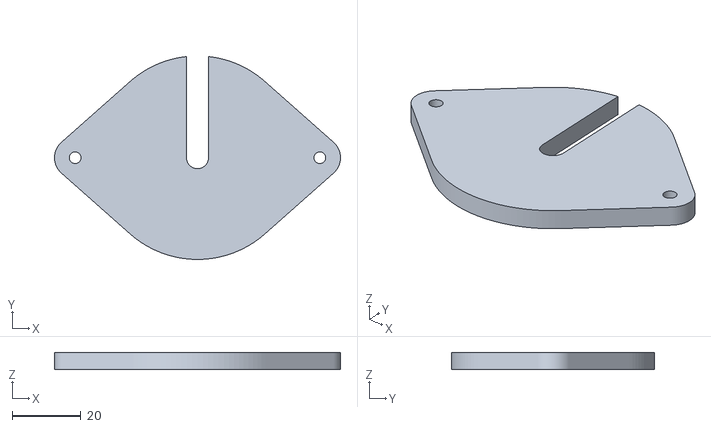
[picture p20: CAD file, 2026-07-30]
STL/Camera_platform.stl
83.2 x 59.0 x 5.00

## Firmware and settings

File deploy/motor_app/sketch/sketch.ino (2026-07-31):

/*
 * Trashbin sorter — MCU side (Arduino UNO Q, arduino:zephyr:unoq).
 *
 * Part of an Arduino App Lab app. The Linux/Python side classifies an item and
 * calls the RPC we expose over the RouterBridge:
 *
 *     Bridge.call("sort", bin)     bin = 0..NUM_BINS-1
 *
 * We rotate the pole to that bin by the SHORTER direction (clockwise or
 * counter-clockwise); on a tie we go CLOCKWISE. The call blocks until the move
 * finishes and returns the bin we landed on (or -1 for a bad bin).
 *
 * For manual/bench control there are also absolute-position RPCs, used by the
 * host-side CLI (deploy/motor_cli.py, driven over ssh):
 *
 *     Bridge.call("step",  n)      stepper -> absolute pulse 0..STEPS_PER_REV
 *     Bridge.call("nudge", d)      stepper -> relative move, signed pulses
 *     Bridge.call("pos",   0)      stepper -> current absolute pulse
 *     Bridge.call("servo", deg)    servo arm -> absolute angle 0..180
 *
 * The stepper's absolute position `currentStep` is the single source of truth;
 * bin moves are just steps at multiples of STEPS_PER_BIN, so manual jogging and
 * bin sorting can never disagree about where the pole is.
 *
 * Stepper wiring (bench-confirmed on this rig — the driver is a
 * TB6600-class, common-anode / active-LOW board):
 *   PUL- = pin 2, DIR- = pin 3, ENA- = pin 4   (PUL+/DIR+/ENA+ tied to +5V).
 *   Driver DIP set to 1/8 microstep => 1600 pulses/rev.
 * The servo arm is wired and ENABLED (pin 6). The homing switch is not wired,
 * so HOMING_ENABLED stays false and homePole() just declares the current spot
 * to be step 0 — flip it once a limit switch is on HOME_PIN.
 */

#include <Arduino_RouterBridge.h>

// Gates the Servo include, the Servo object, and every arm movement. Set to 0
// to build stepper-only (e.g. to bench the pole with the arm disconnected);
// sweepArm() then reports success so a sort still completes.
// NOTE: Servo.h is not bundled with the arduino:zephyr core — sketch.yaml must
// list `Servo (1.3.0)` under `libraries:` or the build fails and the App is
// left stopped.
#define SERVO_ENABLED 1

#if SERVO_ENABLED
#include <Servo.h>
// Constructed in setup(), NOT as a static global. The zephyr backend's Servo
// constructor calls initTimer(), which starts a Zephyr counter device; at
// static-init time that device may not be ready yet, and the failure is silent
// (initTimer returns 0, timer_is_started stays false, and every write() is a
// no-op forever). Deferring construction to setup() runs it after the kernel
// is up. `servoTimerOk` records whether the timer actually started.
static Servo *arm = nullptr;
static bool   servoTimerOk = false;
#endif

// ---- Stepper pins (match the physical wiring: PUL/DIR/ENA = 2/3/4) ----
const int PUL_PIN = 2;
const int DIR_PIN = 3;
const int ENA_PIN = 4;
const int ENA_ACTIVE = LOW;   // common-anode: LOW = driver enabled / holding torque

// Signals are active-LOW (common-anode wiring): a pulse asserts LOW then
// releases HIGH, matching the bench-confirmed driver behaviour.
const int PUL_ASSERT  = LOW;
const int PUL_RELEASE = HIGH;

// ---- Optional peripherals (enable once physically wired) ----
// SERVO_ENABLED is the #define above (it gates the Servo include too).
const int  SERVO_PIN      = 6;   // clear of stepper 2/3/4 and home switch 5
const bool HOMING_ENABLED = false;
const int  HOME_PIN       = 5;   // limit switch to GND, INPUT_PULLUP

// ---- Geometry ----
// The driver DIP is set to 1/8 microstep => 1600 pulses per full revolution.
// Four bins around the circle => 90 deg / 400 pulses each. If you change the
// DIP microstep setting, rescale STEPS_PER_REV.
const int  NUM_BINS       = 4;
const long STEPS_PER_REV  = 1600;
const long STEPS_PER_BIN  = STEPS_PER_REV / NUM_BINS;   // 400 at 1/8 microstep
// Cruise half-period once the ramp is up to speed (800 us => ~625 pulses/s).
const int  PULSE_US       = 800;                         // matches bench timing
// Starting (slowest) half-period, used for the first pulse of every move and
// the last before stopping. Must be below the motor's pull-in rate — raise it
// if moves still stall on startup, lower it if starts feel sluggish.
const int  PULSE_START_US = 2500;                        // ~200 pulses/s
// How many pulses the accel and decel ramps each take.
const long RAMP_STEPS     = 120;

// Direction levels on DIR_PIN. If the pole turns the WRONG way physically,
// just swap these two values (one-line fix, no other logic changes).
const int  CW  = HIGH;
const int  CCW = LOW;

// The pole can stop OFFSET bins short of the target so a servo arm sweeps the
// item the rest of the way. With the servo disabled we stop AT the target.
const int  OFFSET = 0;

// ---- Servo sweep angles (only used when SERVO_ENABLED) ----
// Bench-set 2026-07-30: the arm rests at 160 (its parked/home position) and
// sweeps down to 0, i.e. 160 -> 0 -> 160. This pair is the only thing that sets
// the sweep direction; there is no separate direction flag. Both ends were
// driven by hand on the real linkage first to confirm neither one binds.
const int  ARM_REST   = 160;
const int  ARM_SWEEP  = 0;
// How long the arm stays out at ARM_SWEEP before returning: the time the item
// is actually being pushed off the platform. setArmAngle() already waits
// SERVO_TRAVEL_MS for the arm to get there, so this is dwell, not travel.
const int  SWEEP_MS   = 3000;

// Pulse range handed to attach(). 1000..2000 us is the conservative standard
// range, but on this MG996R it yielded only ~half the commanded travel (a
// 180 deg command swept ~90 deg), so it is widened to the servo's own spec.
// Verified 2026-07-30: full travel, no end-stop stall. If a future horn or
// linkage binds before the ends, narrow this back rather than letting it push.
const int  SERVO_MIN_US = 600;
const int  SERVO_MAX_US = 2400;

// An MG996R holding a stalled position overheats within seconds, so we do not
// hold at all: drive to the angle, allow SERVO_TRAVEL_MS to get there, then
// detach so no pulses are sent at rest. This is what pulling the signal wire
// does by hand. The arm is unpowered between moves and back-drives freely --
// fine for a sweep arm, but it will not hold against a load.
const int  SERVO_TRAVEL_MS = 400;

// Settle time between a failed attach() and the retry, to let the zephyr timer
// actually release before we ask for it again.
const int  SERVO_RETRY_MS  = 50;

// ---- Homing ----
const long HOME_MAX_STEPS = STEPS_PER_REV * 2;  // give up after 2 revs

// Absolute stepper position in pulses, 0..STEPS_PER_REV-1, wrapping. This is
// the single source of truth: `currentBin` is derived from it.
long currentStep = 0;

// Last angle commanded to the servo arm (meaningless while SERVO_ENABLED is 0).
int currentAngle = ARM_REST;

// Whether the stepper is energized (holding torque on). Released by the
// "release" RPC so the pole can be hand-turned; any move re-energizes.
bool motorHeld = true;

// One pulse with an explicit half-period, in microseconds. The ramp in
// rotate() varies this per step; PULSE_US remains the cruise (fastest) value.
void stepPulseUs(int halfPeriodUs) {
  digitalWrite(PUL_PIN, PUL_ASSERT);
  delayMicroseconds(halfPeriodUs);
  digitalWrite(PUL_PIN, PUL_RELEASE);
  delayMicroseconds(halfPeriodUs);
}

void stepPulse() { stepPulseUs(PULSE_US); }

// Rotate `steps` pulses in direction `dir` (CW/CCW level on DIR_PIN), with a
// trapezoidal speed ramp: accelerate from PULSE_START_US to the PULSE_US
// cruise rate over RAMP_STEPS, then decelerate symmetrically before stopping.
//
// Without this the motor was commanded straight from standstill to the full
// 1/PULSE_US rate, which is above its pull-in torque: the rotor cannot stay in
// sync with the field, giving rough/growly motion and — under load — an
// outright stall (buzzing, no rotation). Ramping also crosses the motor's
// low-speed resonance quickly instead of sitting in it.
//
// Short moves never reach cruise: the ramp index is clamped by distance to
// whichever end is nearer, so a 10-pulse jog is simply slow throughout.
void rotate(long steps, int dir) {
  // Re-energize if we were released for hand-turning, and give the driver a
  // moment to establish holding current before the first pulse.
  if (!motorHeld) {
    digitalWrite(ENA_PIN, ENA_ACTIVE);
    motorHeld = true;
    delay(50);
  }
  // Re-assert the pin modes every move. The servo's attach()/detach() on
  // SERVO_PIN reconfigures a zephyr timer, and that was leaving DIR_PIN no
  // longer driven as a GPIO output: digitalWrite() below became a no-op, DIR
  // stayed stuck at its previous level, and every move AFTER a sweep turned
  // the same way -- so a sort went out to the bin and then kept going instead
  // of retracing. Cheap to redo, and it makes the direction independent of
  // whatever the servo did to the pin muxing.
  pinMode(DIR_PIN, OUTPUT);
  pinMode(PUL_PIN, OUTPUT);
  pinMode(ENA_PIN, OUTPUT);
  // pinMode(OUTPUT) leaves the pin driven LOW, and PUL_ASSERT is LOW, so PUL
  // comes out of the reconfigure already asserted: the first
  // digitalWrite(PUL_ASSERT) in the loop below would be a no-op and every move
  // would silently lose its first pulse. Release it explicitly.
  digitalWrite(PUL_PIN, PUL_RELEASE);
  delay(2);                         // let the reconfigured pins settle
  // The TB6600's DIR input is opto-isolated and latches on the TRANSITION, not
  // the level -- see the boot-time priming in setup(). pinMode() above left DIR
  // LOW, which is also CCW, so writing the target level alone gave CW an edge
  // on every move and CCW none at all: CCW moves simply did not turn. Drive the
  // opposite level first so both directions always produce a real edge.
  digitalWrite(DIR_PIN, dir == CW ? CCW : CW);
  delay(2);
  digitalWrite(DIR_PIN, dir);
  // DIR setup before the first pulse. The datasheet wants ~5 us, but the opto
  // was missing changes at 50 us. 2 ms costs nothing next to a move measured in
  // hundreds of milliseconds.
  delay(2);
  for (long i = 0; i < steps; i++) {
    long fromEnd = steps - 1 - i;
    long ramp    = i < fromEnd ? i : fromEnd;   // steps into the nearer ramp
    if (ramp > RAMP_STEPS) ramp = RAMP_STEPS;
    // Linear interpolation: ramp==0 -> PULSE_START_US, ramp==RAMP_STEPS -> PULSE_US.
    int halfPeriod = (int)(PULSE_START_US -
                           ((long)(PULSE_START_US - PULSE_US) * ramp) / RAMP_STEPS);
    stepPulseUs(halfPeriod);
  }
}

// Non-negative modulo, for wrapping positions around the circle.
long wrapMod(long v, long m) { return ((v % m) + m) % m; }

// Rotate from currentStep to absolute pulse `target` (0..STEPS_PER_REV-1) by
// the shorter direction. On an exact tie (half a revolution) we go CLOCKWISE.
void gotoStep(long target) {
  target = wrapMod(target, STEPS_PER_REV);
  long cwSteps = wrapMod(target - currentStep, STEPS_PER_REV);
  if (cwSteps == 0) return;
  long ccwSteps = STEPS_PER_REV - cwSteps;
  if (cwSteps <= ccwSteps) rotate(cwSteps,  CW);    // tie -> clockwise
  else                     rotate(ccwSteps, CCW);
  currentStep = target;
}

// Rotate to `target` in a FORCED direction, however far round that is. Used to
// retrace a move: coming back the way we went keeps the pole from creeping the
// same way turn after turn (which winds up anything routed along it), where
// gotoStep() would happily take the short way and complete a full circle.
void gotoStepVia(long target, int dir) {
  target = wrapMod(target, STEPS_PER_REV);
  long cwSteps = wrapMod(target - currentStep, STEPS_PER_REV);
  long steps = (dir == CW) ? cwSteps : STEPS_PER_REV - cwSteps;
  if (steps == 0 || steps == STEPS_PER_REV) return;
  rotate(steps, dir);
  currentStep = target;
}

// Bin index the pole is nearest to, derived from the absolute step position.
long currentBinOf(long step) {
  return wrapMod((step + STEPS_PER_BIN / 2) / STEPS_PER_BIN, NUM_BINS);
}

// Rotate to bin `target` (0..NUM_BINS-1) — just a step move to its multiple.
void gotoBin(long target) {
  gotoStep(wrapMod(target, NUM_BINS) * STEPS_PER_BIN);
}

// Drive the servo arm to an absolute angle. No-op (returns false) while the
// servo is compiled out.
bool setArmAngle(int deg) {
#if SERVO_ENABLED
  if (arm == nullptr) return false;
  if (deg < 0) deg = 0;
  if (deg > 180) deg = 180;
  // Re-attach for the move, then release again: see SERVO_TRAVEL_MS. The
  // zephyr backend's attach() does NOT always take -- when the timer fails to
  // restart, write() goes nowhere and the arm silently does not move. Verify
  // it, and retry once, or the caller is told a sweep happened that did not.
  if (!arm->attached()) {
    arm->attach(SERVO_PIN, SERVO_MIN_US, SERVO_MAX_US);
    if (!arm->attached()) {
      arm->detach();
      delay(SERVO_RETRY_MS);
      arm->attach(SERVO_PIN, SERVO_MIN_US, SERVO_MAX_US);
    }
  }
  if (!arm->attached()) {
    Monitor.println("servo: ATTACH FAILED, arm did not move");
    return false;
  }
  arm->write(deg);
  currentAngle = deg;
  delay(SERVO_TRAVEL_MS);
  arm->detach();
  return true;
#else
  (void)deg;
  return false;
#endif
}

// Returns false if the arm did not complete its sweep, so the caller can pass
// that up the RPC -- Monitor output does not reach the board's app log, so a
// printed warning would be invisible to anyone driving this remotely.
bool sweepArm() {
#if SERVO_ENABLED
  // Report whether the arm actually swept: a sort that silently skipped the
  // sweep leaves the item sitting on the platform, which looks identical to a
  // successful sort from the outside.
  bool out = setArmAngle(ARM_SWEEP);
  delay(SWEEP_MS);              // dwell out, pushing the item clear
  bool back = setArmAngle(ARM_REST);  // returns and releases; no dwell at rest
  if (!out || !back) Monitor.println("servo: SWEEP INCOMPLETE");
  return out && back;
#else
  return true;   // servo compiled out: nothing to sweep, not a failure
#endif
}

void homePole() {
  if (!HOMING_ENABLED) { currentStep = 0; return; }
  digitalWrite(DIR_PIN, CCW);
  delayMicroseconds(50);
  long moved = 0;
  while (digitalRead(HOME_PIN) == HIGH && moved < HOME_MAX_STEPS) {
    stepPulse();
    moved++;
  }
  currentStep = 0;   // define the stop as step 0 / bin 0
}

// ---- RPC handlers exposed to the Python side ----

// Sort an item into `bin`: rotate to (bin + OFFSET) and sweep. Returns the
// requested bin, or -1 if the bin index is out of range.
int rpcSort(int bin) {
  if (bin < 0 || bin >= NUM_BINS) return -1;
  long stop = ((bin + OFFSET) % NUM_BINS + NUM_BINS) % NUM_BINS;
  // Remember where the platform started so it can come home afterwards: the
  // pole goes out to the bin, the arm sweeps the item off, then the pole
  // returns to its loading position ready for the next item.
  long origin = currentStep;
  // Pick the outbound direction the same way gotoStep() would (shorter way,
  // tie -> clockwise), then come home by the exact reverse of it rather than
  // whichever way is shorter from the far side. Net rotation per sort is zero.
  long target  = wrapMod(stop * STEPS_PER_BIN, STEPS_PER_REV);
  long cwSteps = wrapMod(target - origin, STEPS_PER_REV);
  int  outDir  = (cwSteps <= STEPS_PER_REV - cwSteps) ? CW : CCW;

  gotoStepVia(target, outDir);
  bool swept = sweepArm();
  gotoStepVia(origin, outDir == CW ? CCW : CW);   // retrace, unwinding the trip
  // Come home either way -- leaving the pole parked at the bin on a failed
  // sweep would strand it -- but report the failure, or a sort that left the
  // item sitting on the platform is indistinguishable from a good one.
  if (!swept) return -1;
  Monitor.print("sorted -> bin ");
  Monitor.print(bin);
  Monitor.println(", returned to start");
  return bin;
}

// Rotate straight to `bin` (no offset, no sweep). Returns where we ended up.
int rpcGoto(int bin) {
  if (bin < 0 || bin >= NUM_BINS) return -1;
  gotoBin(bin);
  return (int)currentBinOf(currentStep);
}

// Re-home the pole to the zero stop. Returns the current bin (0).
int rpcHome() {
  homePole();
  return (int)currentBinOf(currentStep);
}

// ---- Manual/bench control (used by the host-side motor_cli.py) ----

// Move the stepper to absolute pulse `step`, 0..STEPS_PER_REV inclusive
// (STEPS_PER_REV wraps to 0 — a full turn is the same place). Shorter
// direction, tie goes clockwise. Returns the position we landed on, or -1 if
// the request is out of range.
int rpcStep(int step) {
  if (step < 0 || step > STEPS_PER_REV) return -1;
  gotoStep(step);
  Monitor.print("step -> ");
  Monitor.println(currentStep);
  return (int)currentStep;
}

// Move the stepper `delta` pulses relative to where it is now (negative =
// counter-clockwise). Returns the new absolute position.
int rpcNudge(int delta) {
  if (delta == 0) return (int)currentStep;
  rotate(delta > 0 ? delta : -delta, delta > 0 ? CW : CCW);
  currentStep = wrapMod(currentStep + delta, STEPS_PER_REV);
  Monitor.print("nudge -> ");
  Monitor.println(currentStep);
  return (int)currentStep;
}

// Report the stepper's absolute position without moving anything. The argument
// is ignored (the Bridge RPC signature needs one).
int rpcPos(int) {
  return (int)currentStep;
}

// Declare wherever the pole is RIGHT NOW to be step 0 / bin 0, without moving.
// This is the manual alternative to a homing switch: de-energize with
// "release", hand-turn the pole to physical zero, then call this. Also used
// after a reflash or App restart, which reset the MCU (and so currentStep)
// while leaving the pole physically where it was.
int rpcZero(int) {
  currentStep = 0;
  Monitor.println("zeroed at current position");
  return 0;
}

// Energize (on != 0) or release (on == 0) the stepper. Released, the driver
// stops holding and the pole can be turned by hand without fighting holding
// torque or skipping steps. Any move re-energizes automatically.
//
// Position is NOT tracked while released — the whole point is that you move it
// by hand — so currentStep is meaningless until you call "zero".
int rpcRelease(int on) {
  digitalWrite(ENA_PIN, on ? ENA_ACTIVE : !ENA_ACTIVE);
  motorHeld = on != 0;
  Monitor.println(motorHeld ? "stepper energized" : "stepper released (free to turn by hand)");
  return motorHeld ? 1 : 0;
}

// Move the servo arm to absolute angle `deg` (0..180). Returns the angle, or
// -1 if out of range / the servo is compiled out (SERVO_ENABLED == 0).
int rpcServo(int deg) {
  if (deg < 0 || deg > 180) return -1;
  if (!setArmAngle(deg)) return -1;
  Monitor.print("servo -> ");
  Monitor.println(deg);
  return currentAngle;
}

void setup() {
  pinMode(PUL_PIN, OUTPUT);
  pinMode(DIR_PIN, OUTPUT);
  pinMode(ENA_PIN, OUTPUT);
  digitalWrite(ENA_PIN, ENA_ACTIVE);
  // Prime DIR by driving it both ways before any move. The TB6600's DIR input
  // is opto-isolated, and the very FIRST level change after boot was being
  // lost: the first move went out correctly, the first move that should have
  // come back went the same way instead, and every direction change after that
  // was fine. Toggling here means a real move is never the first transition.
  digitalWrite(DIR_PIN, CCW);
  delay(20);
  digitalWrite(DIR_PIN, CW);
  delay(20);
  // Toggling the level alone did not clear it, so exercise the whole path --
  // direction change plus real pulses -- a few steps each way. Net movement is
  // zero, and whatever was swallowing the first direction change is spent here
  // instead of on the first real return leg.
  rotate(8, CCW);
  delay(100);
  rotate(8, CW);
  delay(100);
  if (HOMING_ENABLED) pinMode(HOME_PIN, INPUT_PULLUP);
#if SERVO_ENABLED
  // Built here (not statically) so the zephyr counter device is ready — see
  // the note at the Servo declaration. attached() tells us the timer handler
  // actually took the servo, which is reported by the "servo" RPC.
  arm = new Servo();
  arm->attach(SERVO_PIN, SERVO_MIN_US, SERVO_MAX_US);
  servoTimerOk = arm->attached();
  // Park at rest, then release. Before this the sketch attached at boot and
  // never detached, so a blocked or over-driven horn sat stalled at full
  // current from power-on onward -- the overheat we chased.
  setArmAngle(ARM_REST);
#endif

  Bridge.begin();
  Monitor.begin(115200);

  homePole();

  Bridge.provide("sort", rpcSort);
  Bridge.provide("goto", rpcGoto);
  Bridge.provide("home", rpcHome);
  Bridge.provide("step", rpcStep);
  Bridge.provide("nudge", rpcNudge);
  Bridge.provide("pos", rpcPos);
  Bridge.provide("servo", rpcServo);
  Bridge.provide("zero", rpcZero);
  Bridge.provide("release", rpcRelease);

#if SERVO_ENABLED
  Monitor.print("servo: pin ");
  Monitor.print(SERVO_PIN);
  Monitor.println(servoTimerOk ? " attached (timer ok)" : " ATTACH FAILED (timer not started)");
#else
  Monitor.println("servo: compiled out");
#endif

  Monitor.println("trashbin-motor ready");
}

void loop() {
  // RPC requests are serviced by the RouterBridge background thread, so the
  // main loop has nothing to do.
  delay(10);
}

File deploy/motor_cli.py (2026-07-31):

#!/usr/bin/env python3
"""Manual motor control for the UNO Q trashbin, driven over SSH from a laptop.

Standalone by design: this talks to nothing else in `deploy/` (no imports from
motor_bridge, no requests dependency) so you can copy this one file anywhere and
still jog the motors. It shells out to `ssh`, which runs `curl` on the board
against the "Trashbin Motor" App's HTTP port (127.0.0.1:8071) — the same port
the classifier uses, so the App must be running (`start_motor_app.sh` does that
at boot).

Two motors:

  stepper ("LM", the big one on the TB6600 driver) — absolute position in pulses,
      0..1600 for one full revolution at the 1/8 microstep DIP setting. 0 and
      1600 are the same place; each bin is 400 pulses apart (bin 0 = 0,
      bin 1 = 400, bin 2 = 800, bin 3 = 1200). Moves take the shorter way round.
  servo (the arm) — absolute angle 0..180. Only responds once the arm is wired
      and SERVO_ENABLED is flipped to 1 in motor_app/sketch/sketch.ino;
      until then the board answers landed=-1 and this prints a hint.

Usage (one-shot):

    ./motor_cli.py step 800          # stepper -> absolute pulse 800 (half turn)
    ./motor_cli.py nudge -50         # stepper -> 50 pulses counter-clockwise
    ./motor_cli.py servo 160         # arm -> 160 degrees
    ./motor_cli.py bin 2             # stepper -> bin 2 (== step 800)
    ./motor_cli.py sort 2            # full sort move for bin 2 (offset + sweep)
    ./motor_cli.py home              # re-home to step 0
    ./motor_cli.py pos               # print position, move nothing
    ./motor_cli.py health            # is the motor App up?

Usage (interactive — a bare number is a stepper position, which is the fast way
to hunt for bin alignment):

    ./motor_cli.py repl
    motor> 800            # stepper to pulse 800
    motor> +50            # nudge 50 pulses clockwise
    motor> servo 160
    motor> pos
    motor> q

Where to ssh (in precedence order): --ssh, then $MOTOR_SSH, else the default
below.

The board is normally reached over **Tailscale** (`arduino@100.119.45.76`),
which is the default here: it works from any network without port-forwarding or
exposing sshd publicly, and the link is WireGuard-encrypted and
device-authenticated. Plain ssh to the board on the same LAN works just as well
when Tailscale is down — nothing in this CLI depends on Tailscale itself:

    export MOTOR_SSH="arduino@uno-q.local"          # same-LAN fallback
    export MOTOR_SSH_PORT=22
    export MOTOR_SSH_JUMP="root@your.droplet.ip"    # ProxyJump, optional

Exit status is 0 only when the board acknowledged the move.
"""

import argparse
import json
import os
import shlex
import subprocess
import sys

DEFAULT_SSH = os.environ.get("MOTOR_SSH", "arduino@uno-q.local")
DEFAULT_SSH_PORT = os.environ.get("MOTOR_SSH_PORT", "")
DEFAULT_SSH_JUMP = os.environ.get("MOTOR_SSH_JUMP", "")
DEFAULT_URL = os.environ.get("MOTOR_URL", "http://127.0.0.1:8071")

# Geometry mirrored from sketch/sketch.ino. Keep in sync if the driver's
# microstep DIP setting changes.
STEPS_PER_REV = 1600
NUM_BINS = 4
STEPS_PER_BIN = STEPS_PER_REV // NUM_BINS   # 400

# A move blocks until the motor stops, so the ack can be slow: a half turn at
# the sketch's 800us half-period is ~1.3s, and ssh setup adds its own second.
DEFAULT_TIMEOUT = float(os.environ.get("MOTOR_ACK_TIMEOUT", "30"))


class MotorError(RuntimeError):
    """The board could not be reached, or it refused the command."""


def _ssh_argv(target, port, jump):
    argv = ["ssh", "-o", "BatchMode=yes", "-o", "ConnectTimeout=10"]
    if port:
        argv += ["-p", str(port)]
    if jump:
        argv += ["-J", jump]
    argv.append(target)
    return argv


def _remote_curl(path, body, url, timeout):
    """The shell command to run ON the board: curl the motor App, print JSON."""
    cmd = ["curl", "-s", "--max-time", str(int(timeout)), f"{url}{path}"]
    if body is not None:
        cmd += [
            "-X", "POST",
            "-H", "Content-Type: application/json",
            "-d", json.dumps(body, separators=(",", ":")),
        ]
    return " ".join(shlex.quote(c) for c in cmd)


def call(
    path,
    body=None,
    ssh=None,
    port=None,
    jump=None,
    url=DEFAULT_URL,
    timeout=DEFAULT_TIMEOUT,
):
    """Hit one motor-App endpoint over ssh and return its decoded JSON.

    `body` None means GET. Raises MotorError if ssh fails, the App is
    unreachable, or the reply is not JSON.
    """
    argv = _ssh_argv(
        ssh or DEFAULT_SSH,
        DEFAULT_SSH_PORT if port is None else port,
        DEFAULT_SSH_JUMP if jump is None else jump,
    )
    argv.append(_remote_curl(path, body, url.rstrip("/"), timeout))
    try:
        # ssh's own timeout budget is the move timeout plus slack for the
        # handshake, so a hung motor surfaces as curl's error, not a kill.
        proc = subprocess.run(
            argv, capture_output=True, text=True, timeout=timeout + 20
        )
    except subprocess.TimeoutExpired:
        raise MotorError(f"ssh to {ssh or DEFAULT_SSH} timed out after {timeout + 20}s")
    except FileNotFoundError:
        raise MotorError("no `ssh` on PATH")
    out = proc.stdout.strip()
    if proc.returncode != 0 and not out:
        raise MotorError(
            f"ssh failed (exit {proc.returncode}): {proc.stderr.strip() or 'no output'}"
        )
    if not out:
        raise MotorError(
            f"no response from the motor App at {url} — is the 'Trashbin Motor' "
            "app running on the board? (arduino-app-cli app start ~/ArduinoApps/nema17)"
        )
    try:
        return json.loads(out)
    except ValueError:
        raise MotorError(f"non-JSON reply from the board: {out[:200]}")


# ---- One command per motor action -------------------------------------------
# Each returns the value the MCU reported (step position, angle, or bin), and
# raises MotorError when the board refuses the move.


def _landed(data, what):
    if not data.get("ok"):
        raise MotorError(f"{what} refused: {data.get('error', data)}")
    landed = data.get("landed", data.get("step"))
    if landed == -1:
        raise MotorError(
            f"{what} rejected by the MCU (out of range, or the peripheral is "
            "disabled in sketch.ino — see SERVO_ENABLED)"
        )
    return landed


def step(position, **kw):
    """Stepper -> absolute pulse `position`, 0..1600 (shorter direction)."""
    position = int(position)
    if not 0 <= position <= STEPS_PER_REV:
        raise MotorError(f"step must be 0..{STEPS_PER_REV}, got {position}")
    return _landed(call("/step", {"step": position}, **kw), f"step {position}")


def nudge(delta, **kw):
    """Stepper -> `delta` pulses from here; negative is counter-clockwise."""
    delta = int(delta)
    if abs(delta) > STEPS_PER_REV:
        raise MotorError(f"delta must be within +/-{STEPS_PER_REV}, got {delta}")
    return _landed(call("/nudge", {"delta": delta}, **kw), f"nudge {delta:+d}")
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

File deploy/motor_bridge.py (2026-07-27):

"""Linux -> MCU bridge: send a target bin to the motor-control app.

On the UNO Q the STM32 microcontroller isn't reachable as a plain serial tty —
it talks to the Linux side over the Arduino RouterBridge (RPC over an internal
link). That Bridge is only reachable from inside an Arduino App Lab app, so the
motor control lives in the "Trashbin Motor" app (~/ArduinoApps/nema17):

    sketch.ino    exposes  Bridge.provide("sort", ...)     (drives the stepper)
    python/main.py         Bridge.call("sort", bin)  behind an HTTP endpoint

That app publishes an HTTP port to the host, so from here (the classifier loop,
which runs on the host under cron) we just POST the target bin:

    POST http://127.0.0.1:8071/sort   {"bin": <int>}   ->   {"ok":..., "landed":...}

The app rotates the pole to the bin by the shorter direction (clockwise on a
tie) and the request blocks until the move finishes — so waiting on the HTTP
response is our "ack".

Config (env):
    MOTOR_ENABLED     "1" to actually drive motors (default off = camera-only)
    MOTOR_URL         base URL of the motor app (default http://127.0.0.1:8071)
    MOTOR_ACK_TIMEOUT seconds to wait for the move to finish (default 20)

Everything here is best-effort: an unreachable motor app logs a warning and
never crashes the classifier loop.
"""
import os
import time

import requests

MOTOR_ENABLED = os.environ.get("MOTOR_ENABLED", "0") == "1"
MOTOR_URL = os.environ.get("MOTOR_URL", "http://127.0.0.1:8071").rstrip("/")
MOTOR_ACK_TIMEOUT = float(os.environ.get("MOTOR_ACK_TIMEOUT", "20"))

# One pooled session so back-to-back sorts reuse the localhost connection to
# the motor app instead of a fresh TCP handshake on the (blocking) ack path.
_session = requests.Session()

# Dedicated debug log for the motor path. The UNO Q has a single USB port, so
# you can't be on adb AND have the camera plugged in at once — persist every
# motor decision to a file, then reconnect adb later and read it. Set
# MOTOR_LOG="" to disable, or point it elsewhere. Wipe with:  : > motor.log
MOTOR_LOG = os.environ.get(
    "MOTOR_LOG", os.path.expanduser("~/trashbin/motor.log")
)


def _log(msg):
    """Timestamped line to stdout (captured in trashbin.log) and MOTOR_LOG."""
    line = f"{time.strftime('%Y-%m-%dT%H:%M:%SZ', time.gmtime())} [motor] {msg}"
    print(line, flush=True)
    if not MOTOR_LOG:
        return
    try:
        with open(MOTOR_LOG, "a") as f:
            f.write(line + "\n")
    except OSError:
        pass  # logging must never break the sort path


def send_sort(bin_index):
    """Tell the motor app to sort the current item into `bin_index` (0-3).
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

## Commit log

2026-07-08 Add waste classifier notebook, README, gitignore
    Two-stage transfer-learning classifier for the UNO Q trashbin: 256px
    MobileNetV3-Small with EMA, MixUp/CutMix, class-balanced sampling, and
    measured int8 TFLite export. T4-tuned, resumable, with a live compute meter.
2026-07-08 Update README: UNO Q hardware specs, 256px single-model training setup
    Match the notebook's current state — QRB2210 (A53 + Adreno 702) target,
    MobileNetV3-Small only at 256px, EMA/MixUp/class-balanced sampling, T4
    training setup with compute-unit meter, and measured int8/fp32 TFLite export.
2026-07-10 Add UNO Q deploy runtime: confidence-gated clarification loop
    - infer_uno_q.py: TFLite inference matching eval_tf preprocessing,
    softmax confidence, <60% threshold flags for human clarification
    - clarification_client.py: webhook to webapp with offline local queue
    - edge_impulse_upload.py: reference for pushing corrected labels to EI
    - README: document the device -> webapp -> Edge Impulse feedback loop
2026-07-10 Switch to single MobileNetV3-Large target + measured confidence calibration
    - Drop train-both: one deploy model (MobileNetV3-Large IMAGENET1K_V2),
    T4-tuned config (batch 48, 30ep stage 2, EMA 0.9995)
    - New Cell 12b: temperature scaling on val + threshold sweep, saves
    export/confidence_calibration.json
    - Cell 13: per-TFLite-variant recommended threshold in
    quantization_report.json; fix missing int8 output dequantization
    in the confidence path
    - deploy/infer_uno_q.py: TEMPERATURE env var applied before softmax
    - README + notebook docs updated to match
2026-07-11 Fix Colab git auth: use x-access-token PAT form for clone/pull/push
    The bare https://{token}@github.com URL makes git treat the token as a
    username and then block on a password prompt, which fails non-interactively
    in Colab (could not read Password ... No such device or address). Pass the
    PAT as the password with an x-access-token username instead, and gate the
    "Pushed." message on the push actually succeeding.
2026-07-16 Fix Cell 13 quantized export: migrate to litert-torch + torchao PT2E API
    ai-edge-torch was renamed to litert-torch and the PT2E quantization flow
    moved from torch.ao.quantization to torchao. Use torch.export.export()
    (PyTorch 2.6+), convert_pt2e(fold_quantize=False), and litert_torch.convert
    for both fp32 and int8 TFLite variants.
2026-07-16 Make Cell 13 runnable in a fresh session
    Fall back to results/test_results.json and export/confidence_calibration.json
    on Drive when Cells 10/12b haven't been run in the current kernel, and document
    the minimal prerequisite cells (0, 2, 5, 6, 8) in the markdown header.
2026-07-16 Add quantization report, calibration, and labels
2026-07-22 Add motor actuation (stepper + servo) and ignore local docs
    - deploy/motor_control.ino: MCU sketch, homes to zero stop, SORT command,
    stepper STEP/DIR + servo sweep, active-low TB6600 wiring
    - deploy/motor_bridge.py: Linux->MCU serial bridge (opt-in via MOTOR_ENABLED)
    - deploy/bin_map.py: 30 model labels -> 4 physical bins
    - deploy/camera_loop.py: drive the sorter on confident classifications
    - .gitignore: ignore *.md docs except README
2026-07-23 Add plug-and-play on-device deployment (motor App + autostart) and consolidate docs
    The UNO Q's STM32 is only reachable over the Arduino RouterBridge from inside an
    App Lab app, not as a serial tty — so motor control now lives in a proper app:
    - deploy/motor_app/: App Lab app owning the MCU. sketch.ino drives the stepper
    (PUL=9/DIR=10/ENA=8) and exposes Bridge.provide("sort"), rotating to the bin by
    the shorter direction with a clockwise tie-break. python/main.py runs an HTTP
    server on :8071 that calls Bridge.call("sort", bin).
    - deploy/motor_bridge.py: rewritten to POST the target bin to the motor App
    (was the dead /dev/ttyMCU serial path).
    - deploy/run_trashbin.sh, start_motor_a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
    [motor_bridge.py, sketch.ino]
2026-07-24 Fix motor: sketch was driving wrong pins (9/10/8 vs wired 2/3/4)
    The App Lab motor sketch assumed PUL/DIR/ENA=9/10/8 with full-step
    50 steps/bin, but the TB6600 driver is physically wired to pins 2/3/4
    (common-anode, active-LOW) at 1/8 microstep. Sort RPCs acked (landed=N)
    but no pulses reached the driver, so the pole never turned. Match the
    sketch to the known-good motor_control.ino wiring: pins 2/3/4, active-low
    pulses, 400 steps/bin (90 deg/bin).
    Also add timestamped motor-path logging (motor_bridge.py -> ~/trashbin/
    motor.log + stdout) so an acked-but-silent motor is distinguishable from
    an unreached one, and log the actuate/no-actuate decision in camera_loop.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
    [motor_bridge.py, sketch.ino]
2026-07-24 docs: correct stepper wiring to pins 2/3/4 (1/8 microstep, 400 steps/bin)
    The README and electromechanical notes still listed the wrong PUL/DIR/ENA
    9/10/8 full-step config in their summary blocks (the detailed sections were
    already correct). Align them with the fixed sketch and note that a pin
    mismatch acks the RPC but never moves the motor.
2026-07-27 Optimize UNO Q deploy runtime + add deploy test suite
    Behavior-preserving performance and robustness cleanups on the on-device
    runtime (pins/thresholds/model config unchanged):
    - infer_uno_q: fold ImageNet normalization + int8 quantization into one
    per-channel affine (uint8->int8, no float32 intermediate); split
    _resize_crop from preprocess and skip the redundant RGB convert; tolerate
    a missing TFLite runtime at import (clear error only on instantiation);
    log the input dtype / active path at load.
    - camera_loop: pooled requests.Session for dashboard POSTs; downscale before
    grayscale in the motion diff; single cheap read() while watching, reserving
    the 3-frame drain for the actua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
    [motor_bridge.py]
2026-07-30 Add manual motor control over SSH (absolute stepper positioning)
    deploy/motor_cli.py is a standalone host CLI: it ssh'es to the board and
    curls the "Trashbin Motor" App, so both motors can be jogged by hand
    without touching the classifier path. The big stepper is addressed by
    absolute pulse position 0-1600 (one revolution at 1/8 microstep; bins at
    0/400/800/1200), the servo arm by absolute angle 0-180. Interactive mode
    treats a bare number as a position and +N/-N as a jog.
    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
2026-07-30 Rewrite README as final report; move technical docs to docs/
    Restructure README to the course final-report format (team, overview,
    goals, hardware, mechanical design, accomplishments, challenges,
    lessons learned, next steps, reconstruction, timeline).
    Fill in measured results rather than estimates:
    - 89.08% test acc / 0.890 macro-F1 / 4.24M params from results/
    - three-variant quantization table from exports/quantization_report.json
    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
2026-07-30 Create STL
2026-07-30 Add motion ramp, servo support, and manual zeroing to motor app
    Stepper moves previously started instantly at the full 625 pulses/s, above
    the motor's pull-in torque: rough motion, and stalls under load. rotate()
    now runs a trapezoidal profile (PULSE_START_US -> PULSE_US over RAMP_STEPS,
    decelerating symmetrically). A 400-pulse bin move goes ~0.71s -> ~1.15s;
    the slower travel is wanted, it stops the load being thrown.
    Enable the servo arm (SERVO_ENABLED=1) on D6. Servo.h is not bundled with
    the arduino:zephyr core, so sketch.yaml -- previously missing from the repo
    entirely -- now pins Servo (1.3.0); without it the build fails and a failed
    build leaves the App stopped. The Servo object is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
    [sketch.ino]
2026-07-30 Add zero/release to the motor CLI and fix the stale route test
    The board gained /zero and /release for manual zeroing, but nothing on the
    host side could reach them — MOTOR_CONTROL_MAP says both are required after
    every boot and reflash, which meant hand-writing curl over ssh. Expose them
    as CLI and REPL commands; a bare `release` drops holding torque (the common
    case, for hand-turning the pole) and `release 1` re-energizes.
    test_motor_app asserted an exact _POST_ROUTES set that predated those two
    routes, so the suite was failing. The routes were right; the test was stale.
    Also record that the servo, reflashed on D6, now returns the commanded angle
    instead of -1 — the firmware is attac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
    [motor_cli.py, test_motor_cli.py]
2026-07-30 Fix servo overheat and half travel; return the pole after a sort
    The servo cooked itself because the sketch attached at boot and never
    detached: pulses went out continuously, so a horn that could not reach its
    commanded angle stalled at full current indefinitely. Pulling the signal wire
    by hand stopped it, which is what pointed at the pulse train. setArmAngle()
    now attaches, writes, waits SERVO_TRAVEL_MS for travel, then detaches, so the
    arm is unpowered at rest. It no longer holds against a load between moves --
    acceptable for a sweep arm.
    attach() was also using the library's default pulse range, which yielded only
    about half the commanded travel on this MG996R. Pinned to 600..2400 us.
    S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
    [sketch.ino]
2026-07-30 Return the pole by retracing the outbound move after a sort
    gotoStep() always takes the shorter way round, so the trip home from a bin
    could continue in the same direction rather than coming back -- a sort to
    bin 2 (the exact tie, 800 pulses either way) went out clockwise and home
    clockwise, a full revolution every time. Anything routed along the pole
    winds up.
    gotoStepVia() forces a direction however far round that is. rpcSort() picks
    the outbound direction the way gotoStep() would, then returns by its exact
    reverse, so net rotation per sort is zero.
    Verified on the bench, all four bins ending back at step 0. Timings confirm
    the outbound legs are unchanged: bin 0 no travel (4.6 s, servo o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
    [sketch.ino]
2026-07-31 Fix CCW stepper moves, repair boot autostart, and consolidate the webapp
    The stepper could not turn counter-clockwise. rotate() re-asserts pinMode on
    DIR_PIN each move (added to survive the servo's pin muxing), and pinMode leaves
    the pin driven LOW -- which is also CCW. So a CW move produced a LOW->HIGH edge
    every time while a CCW move produced no transition at all, and the TB6600's
    opto-isolated DIR input latches on the edge, not the level. Drive the opposite
    level first so both directions always get a real edge. The same pinMode block
    left PUL asserted (PUL_ASSERT is LOW), making the loop's first pulse a no-op and
    silently dropping one step per move; release it explicitly.
    Convert the she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
    [motor_bridge.py]
2026-08-01 Rewrite README as the final report
    Retitle to the ECE 180 Summer 2026 final-project format and restructure to
    match the class README template: Original Goals / Goals We Met, Gantt Chart
    and Videos and Resources ahead of Project Reconstruction, and a Problem/Fix
    troubleshooting table.
    Add the UCSD logo, a hero demo clip, sorting demos, design renders, the
    double-motored pole photo, the wiring photo, and the Gantt chart. Demo GIFs
    are downscaled into docs/images/web/ for the page; full-resolution originals
    stay in docs/images/.
    Document the build: power distribution off one terminal into two bucks, the
    powered-USB-hub requirement for the camera, the 66 W draw against a 60 W
    supply that pinne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
